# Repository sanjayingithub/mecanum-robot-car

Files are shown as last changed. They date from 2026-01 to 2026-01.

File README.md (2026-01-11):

# ESP32 Mecanum Wheel Robot Car

A complete remote-controlled mecanum wheel robot car system using ESP32 microcontrollers with ESP-NOW wireless communication protocol.

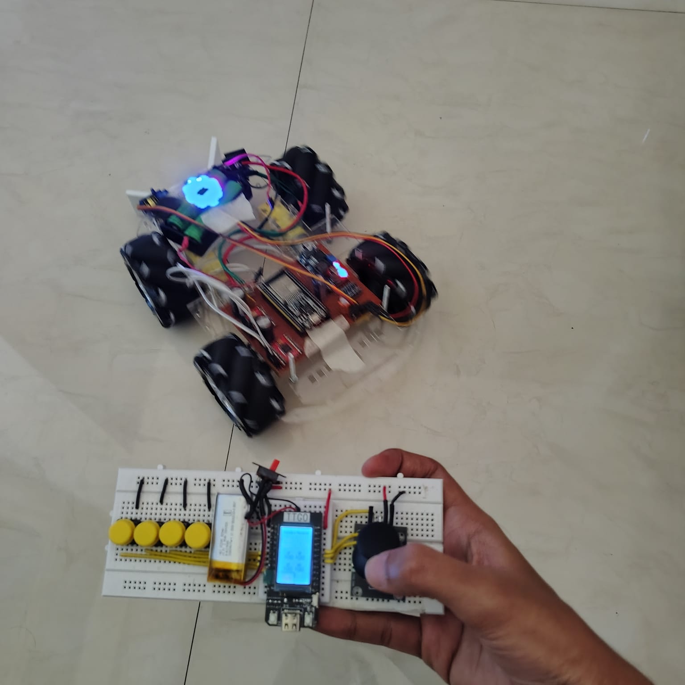
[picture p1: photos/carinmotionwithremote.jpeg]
Youtube Video (https://www.youtube.com/watch?v=mn05_ho8lYk)

Click on image for video

## 📋 Overview

This project consists of two main components:
- **Experiment_car_copy**: The robot car controller (ESP32 DevKitC)
- **ESP_NOW_remote**: The wireless remote control (TTGO T-Display)

> 📖 **For detailed build process, issues encountered, and recommendations, see [BUILD_LOG.md](BUILD_LOG.md)**

This is a derived and enhanced version of the original mecanum wheel robot car designed by [DroneBot Workshop](https://dronebotworkshop.com). Special thanks to them for the excellent tutorial!

## 🚗 Features

### Robot Car (Experiment_car_copy)
- **4-Wheel Mecanum Drive System** with omnidirectional movement
- **6 Driving Modes**:
  - Standard Mode (full directional control)
  - Rotate Mode (in-place rotation)
  - Front/Rear Pivot Modes
  - Left/Right Pivot Modes
- **8 WS2812B RGB Status LEDs**:
  - Mode indicator (cyan/green/orange/violet/light blue/yellow)
  - Battery health indicator (green/yellow/red/flashing red)
  - Flapper mechanism indicator (indigo when active)
  - Speed limiter indicator (white/magenta)
  - Motor direction indicators (blue=forward, green=reverse, red=stopped)
- **Servo-controlled Flapper Mechanism** (kick action)
- **Real-time Battery Monitoring** with voltage divider
- **Motor Control**: TB6612FNG dual motor drivers
- **Watchdog Timer** for system stability
- **ESP-NOW Communication** with signal timeout protection

### Remote Control (ESP_NOW_remote)
- **TTGO T-Display Module** with integrated TFT screen
- **Analog Joystick Control** for precise movement
- **Multiple Display Modes**:
  - Graph mode (motor speed visualization)
  - Speed display mode
  - Compact mode (portrait orientation)
- **Speed Limiter Function** (adjustable maximum speed)
- **Battery Voltage Display** (both remote and car)
- **Real-time Motor Status** visualization
- **Mode Switching Buttons** (joystick button, rotate button)
- **Screen Toggle** functionality for power saving

## 🔧 Hardware Requirements

### Robot Car
- ESP32 DevKitC (or compatible)
- 2x TB6612FNG Motor Driver Modules (or L298N)
- 4x DC BO Motors with mecanum wheels
- 1x Servo motor (for flapper mechanism)
- 8x WS2812B NeoPixel LEDs
- 2S Li-ion Battery (7.4V nominal)
- Voltage divider circuit (100kΩ + 47kΩ resistors)
- LM2596 (for stepping down the voltage to 5V for ESP32, Neopixel, servo)

### Remote Control
- TTGO T-Display ESP32 Module
- Analog Joystick Module (X/Y axis + button)
- 4 Push buttons for additional controls
- Battery (3.7V LiPo)

## 📌 Pin Connections

### Car (ESP32 DevKitC)
```
Motors:
- Right Front: PWM=19, IN1=32, IN2=23
- Left Front:  PWM=26, IN1=33, IN2=25
- Right Rear:  PWM=27, IN1=12, IN2=14
- Left Rear:   PWM=4,  IN1=13, IN2=2

NeoPixels: Pin 5
Servo: Pin 18
Battery ADC: Pin 34
```

### Remote (TTGO T-Display)
```
Joystick:
- X-Axis: Pin 33
- Y-Axis: Pin 32
- Switch: Pin 12

Buttons:
- Flap: Pin 15
- Rotate: Pin 2
- Speed Limiter: Pin 13
- Display Mode: Pin 0 (built-in)
- Screen Toggle: Pin 35 (built-in)

Battery ADC: Pin 34
```

## 🚀 Getting Started

### Prerequisites
- [PlatformIO IDE](https://platformio.org/) (VS Code extension recommended)
- USB cable for programming
- Git (for cloning repository)

### Installation

1. **Clone the repository**
   ```bash
   git clone https://github.com/yourusername/mecanum-robot-car.git
   cd mecanum-robot-car
   ```

2. **Update MAC Addresses**
   - In `Experiment_car_copy/src/main.cpp`, update line 133:
     ```cpp
     uint8_t broadcastAddress[] = {0x08,0xD1,0xF9,0x6A,0x6E,0x94}; // Remote MAC
     ```
   - In `ESP_NOW_remote/src/main.cpp`, update line 68:
     ```cpp
     uint8_t broadcastAddress[] = {0xD4,0xE9,0xF4,0xA3,0x2F,0xF4}; // Car MAC
     ```
   
   *To find MAC address: Upload a simple sketch that prints `WiFi.macAddress()`*

3. **Install Required Libraries**
   
   Libraries are automatically managed by PlatformIO. Required dependencies:
   - NeoPixelBus (for WS2812B LEDs)
   - ESP-NOW (built-in)
   - TFT_eSPI (for remote display)

4. **Configure TFT_eSPI** (Remote only)
   - Copy `TFT_eSPI_Setup.h` to your TFT_eSPI library folder
   - Or modify `User_Setup.h` in the library for TTGO T-Display

5. **Upload Code**
   ```bash
   # For the car
   cd Experiment_car_copy
   pio run --target upload
   
   # For the remote
   cd ../ESP_NOW_remote
   pio run --target upload
   ```

## 🎮 Usage

### Remote Control Operation

**Joystick:**
- Move in any direction for mecanum wheel control
- Push button to cycle through all 6 modes

**Buttons:**
- **Rotate Button**: Quick cycle (Standard → Rotate → Front Pivot)
- **Flap Button**: Activate servo flapper mechanism
- **Speed Limiter**: Toggle speed restriction on/off
- **Display Mode**: Cycle through display layouts
- **Screen Toggle**: Turn display on/off for battery saving

### LED Indicators (Car)

**Status LEDs:**
- **NEO_STATUS (0)**: Current driving mode
  - Cyan = Standard, Green = Rotate, Orange = Front Pivot
  - Violet = Rear Pivot, Light Blue = Right Pivot, Yellow = Left Pivot
- **NEO_STATUS1 (2)**: Battery health
  - Green (>7.2V), Yellow (7.0-7.2V), Red (<7.0V), Flashing Red (<6.5V)
- **NEO_STATUS2 (4)**: Flapper status
  - Indigo = Active, Mode color = Idle
- **NEO_STATUS3 (6)**: Speed limiter
  - Magenta = Limited, Mode color = Normal

**Motor LEDs:**
- Blue = Forward, Green = Reverse, Red = Stopped

**Error State:**
- All LEDs turn RED when remote connection lost (>500ms timeout)

## 🔋 Battery Monitoring

The system monitors both car and remote battery voltages:
- Car: 2S Li-ion (7.4V nominal, 6.0V cutoff)
- Remote: 1S LiPo (3.7V nominal, 3.0V cutoff)

Voltage divider calculations are calibrated in code. Adjust `batteryConversionFactor` if readings are inaccurate.

## ⚙️ Configuration

### Speed Limiter
Adjust maximum speed in `ESP_NOW_remote/src/main.cpp`:
```cpp
const int speedLimitX = 100;  // 0-254 range
const int speedLimitY = 100;
```

### Servo Settings
Flapper servo parameters in `Experiment_car_copy/src/main.cpp`:
```cpp
const int kickAngle = 50;        // Kick position (degrees)
const long kickDelay = 500;      // Kick duration (ms)
const long kickCooldown = 50;    // Cooldown time (ms)
```

### LED Brightness
Reduce brightness by adjusting RGB values in color definitions (currently set to 20%).

## 🐛 Troubleshooting

**No Communication:**
- Verify MAC addresses are correct
- Check WiFi is not interfering
- Ensure both devices powered on
- Check serial monitor for ESP-NOW init errors

**Motors Not Moving:**
- Check motor driver connections
- Verify power supply is adequate (2A+ recommended)
- Test motor drivers independently
- Check PWM channel conflicts

**LEDs Not Working:**
- Verify NeoPixel power and ground
- Check data pin connection (Pin 5)
- Remove any resistors in power rail (causes voltage drop)
- Test with simple NeoPixel sketch

**Display Issues (Remote):**
- Verify TFT_eSPI configuration
- Check backlight control (Pin TFT_BL)
- Test display with TFT_eSPI examples

## 📝 Code Structure

### Experiment_car_copy
- ESP-NOW communication callbacks
- Motor control functions (6 modes)
- LED status management
- Battery monitoring
- Servo flapper control
- Watchdog timer implementation

### ESP_NOW_remote
- Joystick input processing with deadzone
- Button debouncing logic
- Display rendering (3 modes)
- ESP-NOW data transmission
- Battery voltage monitoring

## 🤝 Contributing

Improvements welcome! Areas for enhancement:
- PID-based speed control
- IMU integration for stability
- Obstacle detection sensors
- Autonomous navigation modes
- Mobile app integration

## 📄 License

This project is open source. Feel free to modify and distribute.

## 🙏 Acknowledgments

- Based on mecanum wheel robot tutorial by [DroneBot Workshop](https://dronebotworkshop.com)
- NeoPixelBus library by Michael C. Miller
- TFT_eSPI library by Bodmer
- ESP-NOW protocol by Espressif

## 📧 Contact

For questions or suggestions, please open an issue on GitHub.

---

**Happy Building! 🤖**

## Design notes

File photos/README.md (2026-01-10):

# Build Photos

This folder contains photos documenting the build process and final assembly.

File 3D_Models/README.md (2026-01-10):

# 3D Models Directory

This folder contains STL files for custom 3D printed components used in the mecanum robot car build.

## Files

### motor_coupler.stl
- Motor shaft to wheel hub coupler
- Print with 80% infill for strength
- Material: PLA or PETG

### flapper_arm.stl
- Servo-mounted flapper mechanism for ball kicking
- Print with 80% infill
- Material: PETG recommended (more impact resistant)

## Print Settings

**Recommended:**
- Layer Height: 0.2mm
- Infill: See individual file notes
- Supports: As needed
- Raft/Brim: Use for parts with small contact area

**Notes:**
- All files designed for standard FDM printers
- No special hardware required
- Test fit before full assembly
- Sand contact surfaces for smooth fit

---

*Add your STL files to this directory*

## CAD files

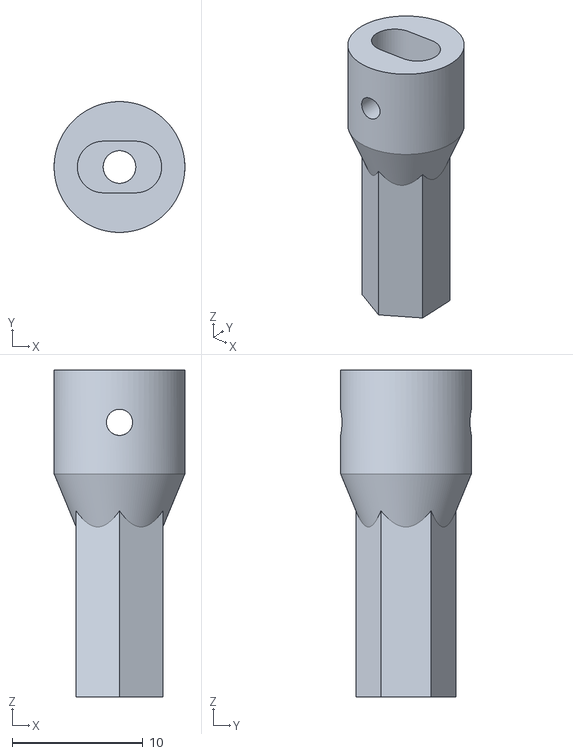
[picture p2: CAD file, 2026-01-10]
3D_Models/couplerAdityaRao.stl
10.0 x 10.0 x 25.0

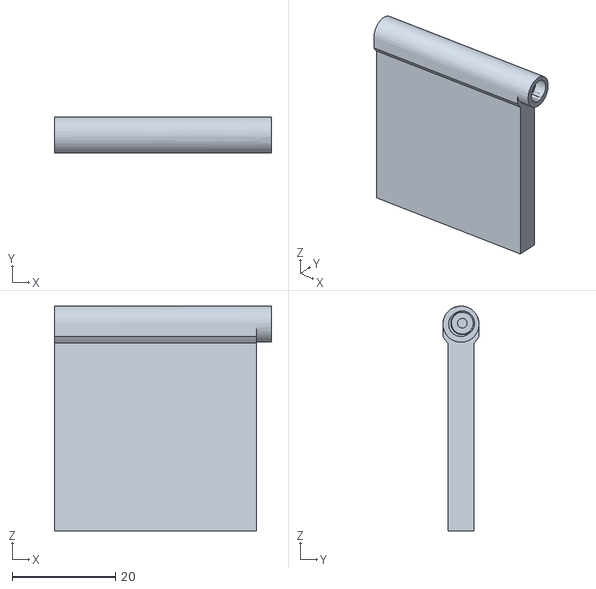
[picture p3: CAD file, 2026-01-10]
3D_Models/flapper.stl
42.0 x 7.00 x 43.5

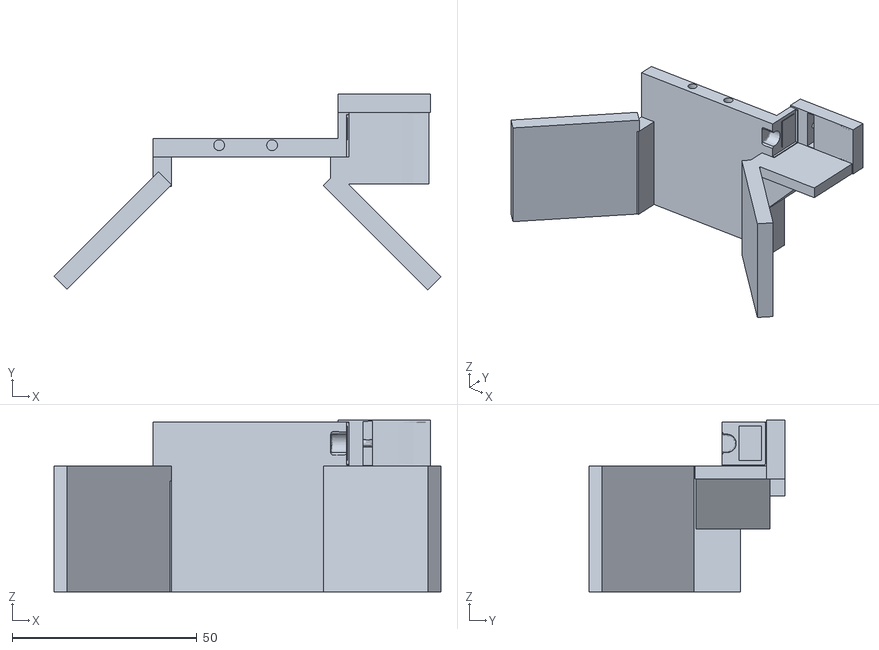
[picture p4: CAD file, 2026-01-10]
3D_Models/flapper_body.stl
104.6 x 53.0 x 46.5

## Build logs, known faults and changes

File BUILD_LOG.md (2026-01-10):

# Build Log & Documentation

## 📝 Project Overview

This is a derived and enhanced version of the Mecanum Wheel Robot Car originally designed by [DroneBot Workshop](https://dronebotworkshop.com). The original tutorial provided an excellent foundation, and this build includes several modifications and improvements based on real-world testing and usage.

**Original Tutorial:** [DroneBot Workshop - Mecanum Wheel Robot Car](https://dronebotworkshop.com/mecanum/)

> **Special Thanks:** A huge thank you to DroneBot Workshop for the comprehensive tutorial and detailed explanations that made this project possible!

#### **Another valuable resource** [IITM Student Outreach Program](https://drive.google.com/drive/folders/1NdA0Y0AUDSWe7Uvx9wfMEFJxht2Ays-z)

#### **People who help me make this into a reality**
  - Sajeev
  - Nisha
  - [Tejassh](https://github.com/TejazerX)
  - [Aditya](https://www.linkedin.com/in/aditya-mahto-55274b391/)
  - Diya ma'am
  - Jinesh sir
  - Nandana
  - [Aditya](https://www.linkedin.com/in/adityaraoiitm/)
  - [Phil](https://www.printables.com/@PhilM)

---

## 🛠️ Build Process & Modifications

### Mechanical Components

#### Frame & Chassis
- **Material:** Laser-cut acrylic/MDF panels
- **Process:** 
  - Designed frame layout for mecanum wheel configuration
  - Sent design for laser cutting service
  - **Required extensive sanding** of all cut edges to remove char marks and ensure smooth finish
  - Assembly with M3 standoffs (I wasn't able to get M3 standoffs so used 10mm screws and nuts) and screws
- **File:** [I didn't design it, got it from Phil M](https://www.printables.com/model/186945-4wd-buggy-chassis-arduino)

**💡 Recommendation:** Consider purchasing a **pre-made mecanum wheel car kit** instead of sourcing individual components. It's often:
- **Cheaper** than buying parts separately
- Comes with properly fitted parts
- Saves significant time on fabrication
- Eliminates alignment issues

Popular kit options:
- 4WD Mecanum Wheel Robot Car Kit (various sellers on AliExpress, Amazon, robu, makerbazar)
- Pre-assembled chassis with motor mounts
- Often includes motors and wheels
- Also the fittings, the screws and nuts are quite difficult to source by themself especially locally and they are more expensive too.

#### Custom 3D Printed Parts

##### 1. Motor-to-Wheel Coupler
- **Purpose:** Connect DC motors to mecanum wheel hubs
- **Material:** PLA/PETG
- **Print Settings:**
  - Layer height: 0.2mm
  - Infill: 50-80% (needs to handle torque)
  - Supports: Required for shaft interface
  - Print orientation: it in a horizontal manner as i had issues of it snapping off due to torque. 
  
**Issues Faced:**
- Initial couplers were too tight - had to sand down motor shaft interface
- Wheel wobble due to loose fit - added plumbers tape for grip
- Kept on breaking so applied M-Seal will have to fix it as the wheels aren't oriented straight.

**Files:** `3D_Models/motor_coupler.stl`  [I didn't design this,got them for IITM School connect course curriculum](https://drive.google.com/file/d/1HanFR_hteSeybVQaEPewp7Q1eFs2xh4M/view?usp=drivesdk)

##### 2. Servo Flapper Mechanism
- **Purpose:** Ball kicking mechanism mounted on servo
- **Design:**
  - Servo horn attachment point
  - Extended arm for reach
  - Reinforced impact surface
- **Material:** PETG (more flexible and impact-resistant than PLA)
- **Print Settings:**
  - Layer height: 0.2mm
  - Infill: 80% (needs strength for impacts)
  - Print orientation: Flat to ensure layer strength perpendicular to impact

**Issues Faced:**
- PLA version cracked after repeated impacts - switched to PETG
- Initial design too long - reduced servo strain by shortening arm
- Servo jitter under load - adjusted PWM frequency

**Files:** `3D_Models/flapper_arm.stl` *This is my first model so there are lots of problems, shall update it in future*

[Body](https://github.com/sanjayingithub/mecanum-robot-car/blob/main/3D_Models/flapper_body.stl)
[Flapper](https://github.com/sanjayingithub/mecanum-robot-car/blob/main/3D_Models/flapper.stl)

---

## ⚡ Electronics Assembly

### Power Distribution
- **Main Battery:** 2S Li-ion (7.4V, 2200mAh recommended)
- **Issue:** Initial setup had voltage drop under load
  - **Solution:** Added capacitors (470µF) near motor drivers
  - Used thicker gauge wires (18 AWG) for motor power

### Motor Drivers
- **Used:** 2x TB6612FNG modules
- **Mounting:** designed the entire thing on a protoboard

### LED Wiring
- **Critical Issue:** Added 220Ω resistor in NeoPixel power rail thinking it was needed
  - **Problem:** Caused voltage drop affecting blue channel brightness
  - **Solution:** Removed resistor - NeoPixels work best with direct 5V connection
  - **Lesson:** Always check component datasheets before adding "protective" components

### Servo Integration
- **Flapper Servo:** Connected to Pin 18
- **Power:** Direct from battery through servo connector
- **Issue:** Servo buzzing at idle
  - **Solution:** Adjusted duty cycle calculation for 0° position
  - Used 16-bit LEDC resolution for smoother control

---

## 🎨 Aesthetics & Finishing

### Sanding of motor mounts and 3d prints
- **Time Required:** Approximately 3-4 hours for all laser-cut parts
- **Tip:** Wet sanding works better for acrylic, prevents melting from friction

### LED Brightness Tuning
- **Initial:** Full brightness (255 RGB values)
- **Problem:** Way too bright, uncomfortable to look at
- **Solution:** Reduced to 20% brightness (51 RGB values)
- **Result:** Easier on eyes while maintaining visibility

---

## 📸 Build Photos

### Assembly Stages

#### 1. Charger
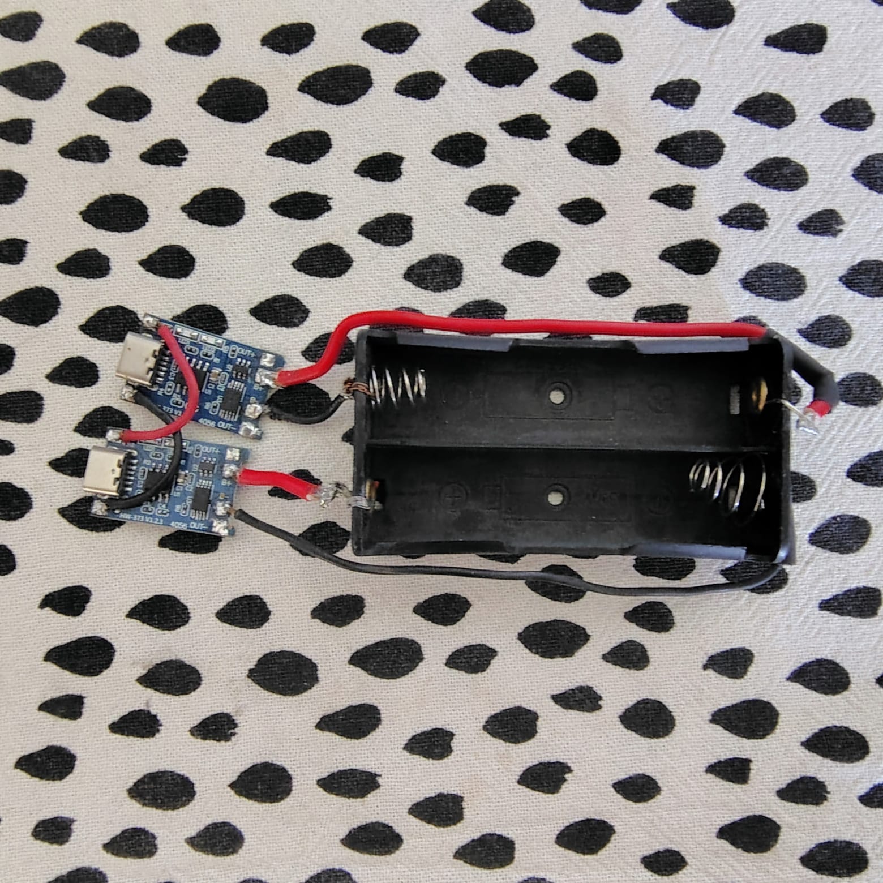
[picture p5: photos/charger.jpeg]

- Its basically TP4056 and a battery holder
- 2 of the modules are connected in parallel
- The modules doesn't have [5.1K 1% resistors in CC lines](https://forum.digikey.com/t/simple-way-to-use-usb-type-c-to-get-5v-at-up-to-3a-15w/7016) so a type A to type C cable will only work as it doesn't support PD

#### 2. Electronics Layout
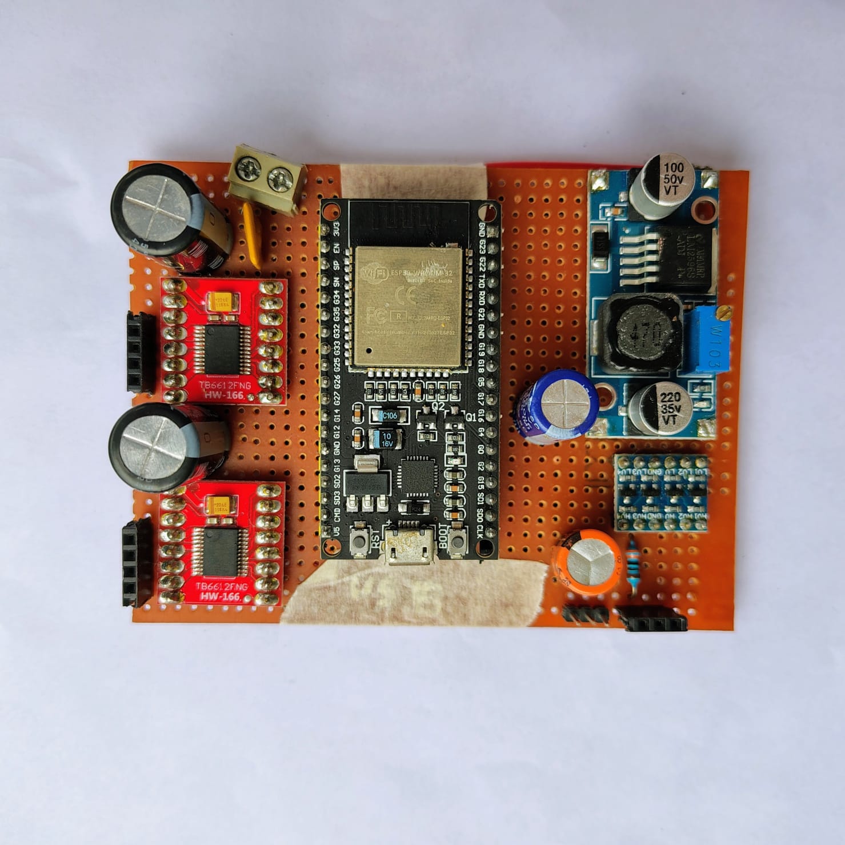
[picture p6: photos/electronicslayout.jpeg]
electronics layout

- Motor drivers positioned
- ESP32 mounted
- Wiring harness layout

#### 3. LED Neopixel
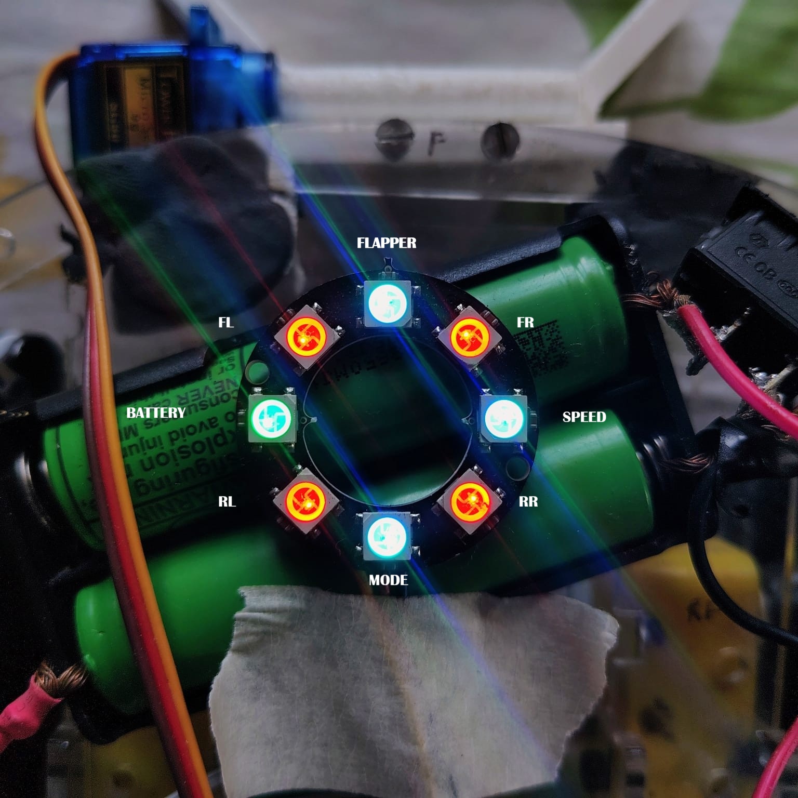
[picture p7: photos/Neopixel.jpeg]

- NeoPixel ring placement

#### 4. Flapper Mechanism
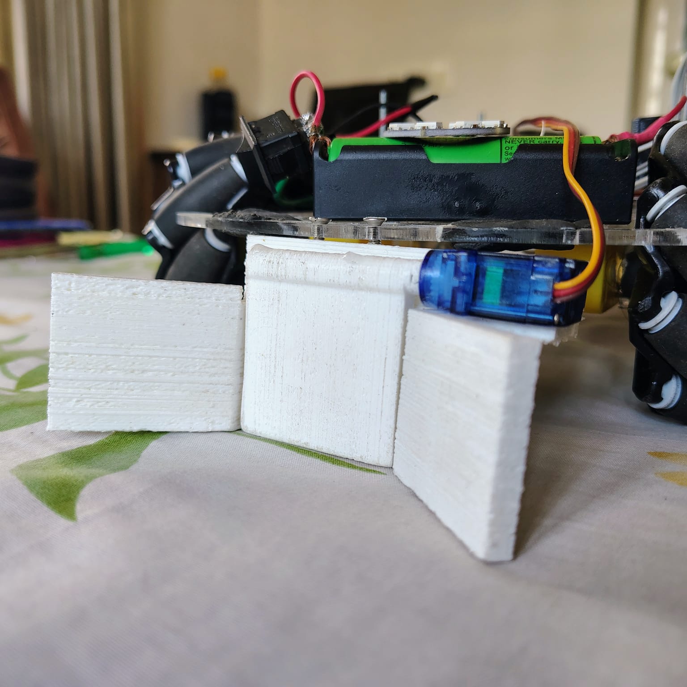
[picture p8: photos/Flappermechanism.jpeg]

- 3D printed flapper arm
- Servo mounting

#### 5. Completed Build - Top View
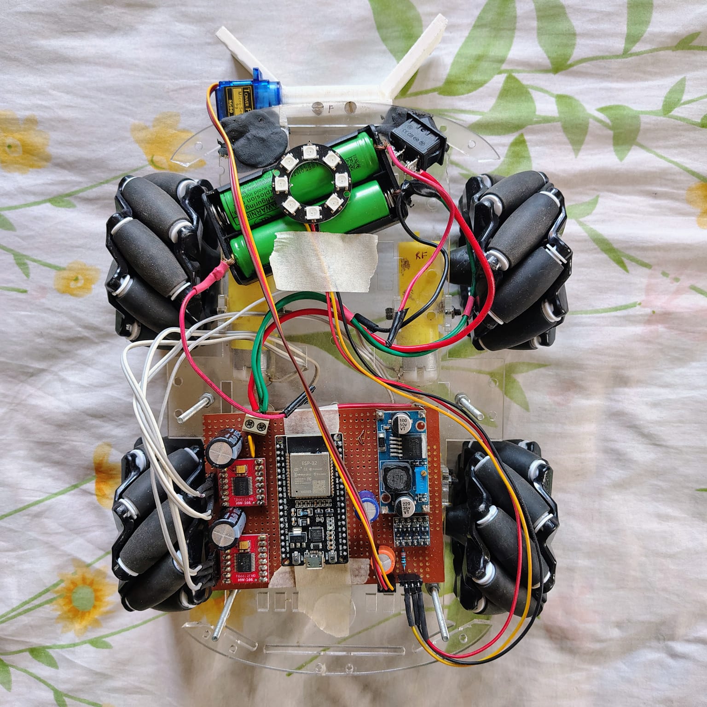
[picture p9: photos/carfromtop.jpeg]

- Fully assembled robot
- All components in place

#### 6. Completed Build - Side View
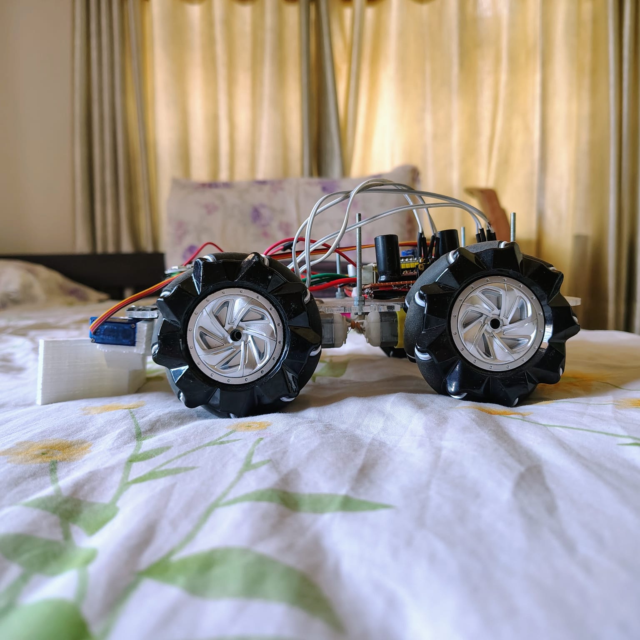
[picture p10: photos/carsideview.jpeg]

- Ground clearance

#### 7. Remote Control
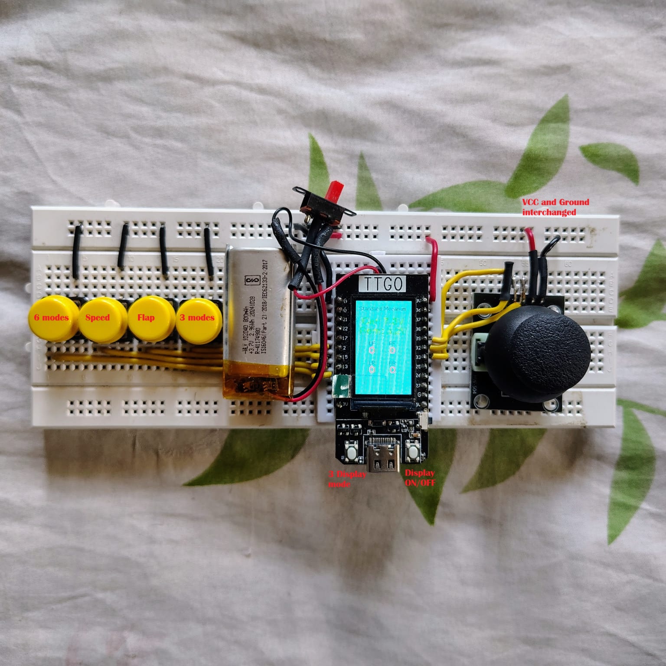
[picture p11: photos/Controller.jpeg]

- TTGO T-Display with joystick
- Button layout

#### 8. Action Shots
electronics layout
- Robot in motion
- LED indicators active
- Flapper mechanism deployed

#### 9. Display
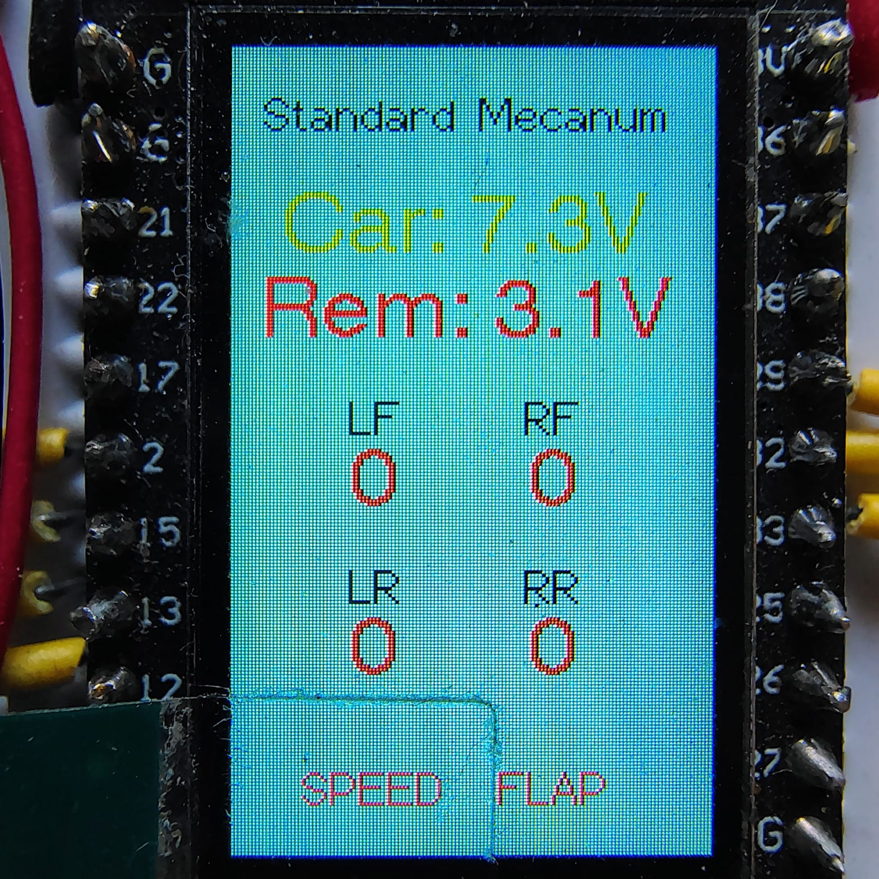
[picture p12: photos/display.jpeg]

- This is the default mode the other 2 are same as Dronebotworkshop
- The title and background color changes in differnt modes
- The colour of motor postion changes with direction and values change with speed
- Lower corner shows the indication of Speed and flapper modes

#### 10. Wiring
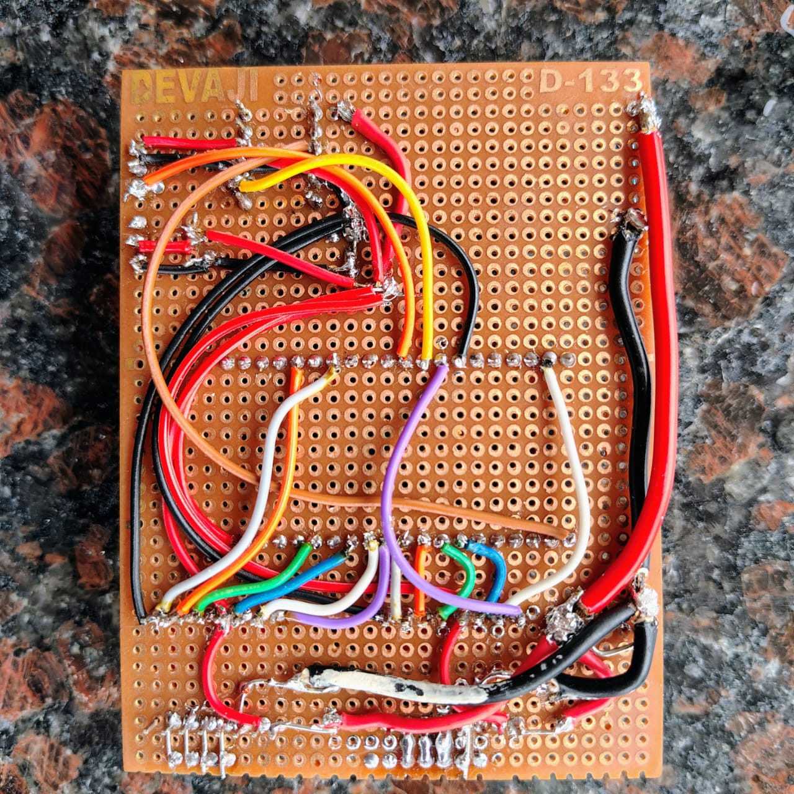
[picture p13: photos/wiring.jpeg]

- This is my first experience with protoboarding
- The soldering works even though it look like a piece of crap
- This was taken before adding the voltage divider

#### 11. Resistive divider
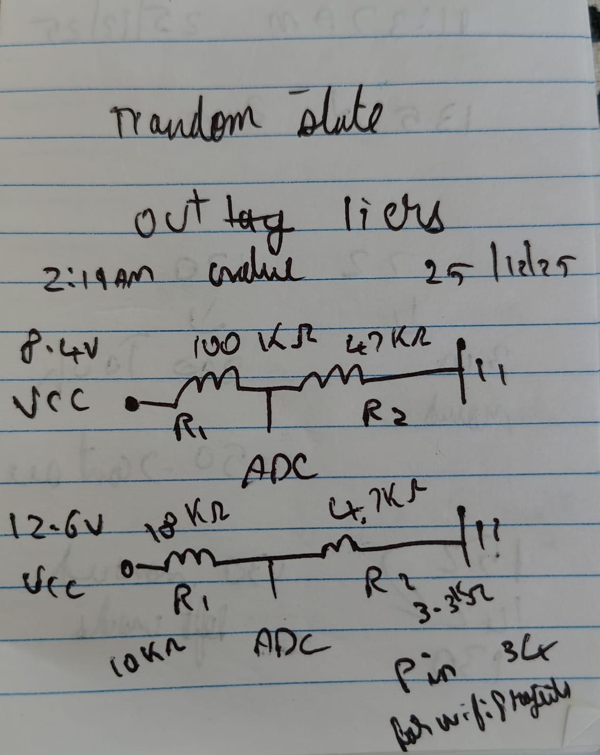
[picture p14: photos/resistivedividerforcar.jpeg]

- The first resistor values are being used here as 2 18650 batteries are only used
- If you decide to go with 3 18650 in series use the second resistor values

#### 12. Pin marking
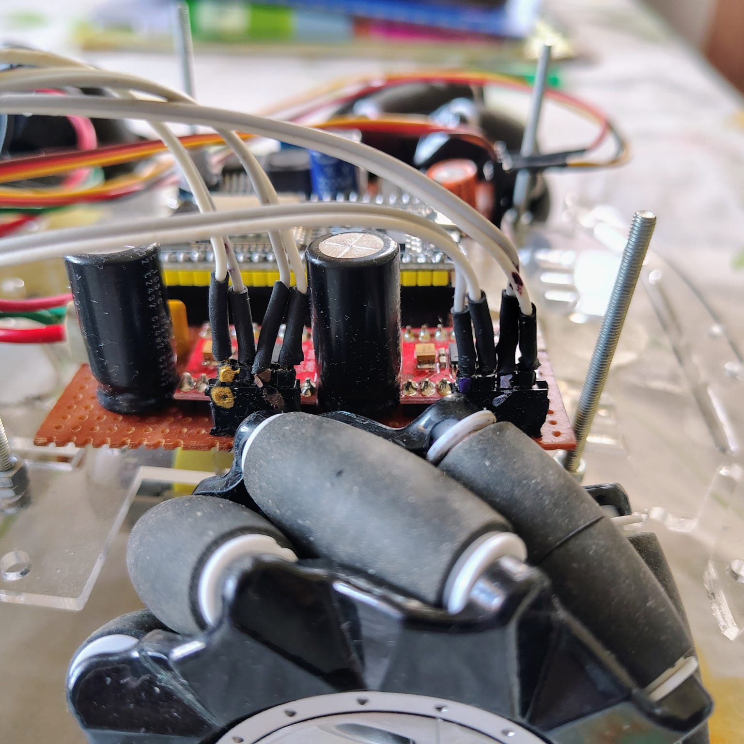
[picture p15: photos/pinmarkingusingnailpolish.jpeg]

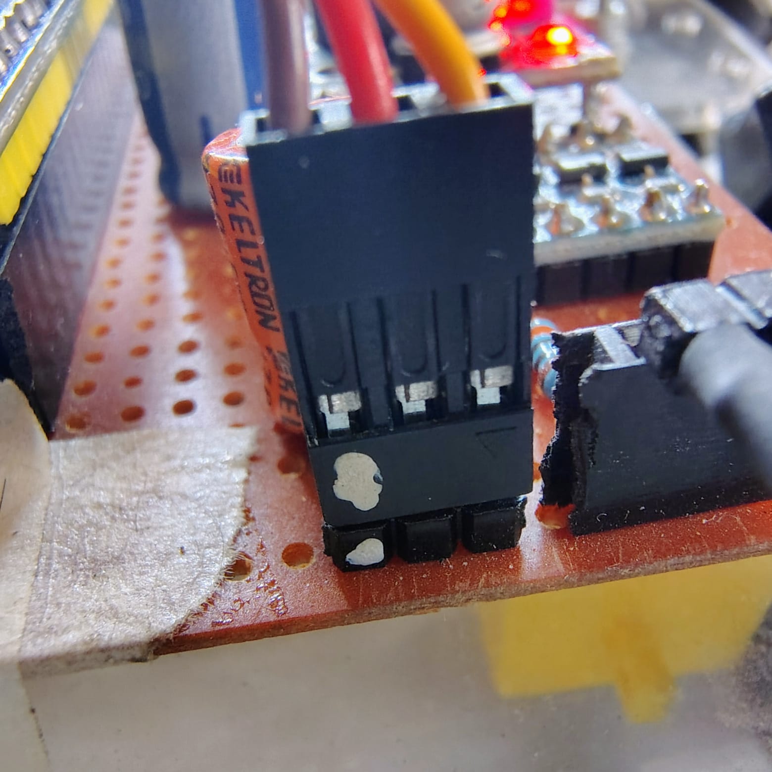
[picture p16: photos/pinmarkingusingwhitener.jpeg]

- Used a combination of whitener and nail polish to oriet and connect the wires.

---

## 🐛 Issues Encountered & Solutions

### Hardware Issues

#### 1. Motor Alignment
**Problem:** Mecanum wheels not driving straight
- **Cause:** Uneven motor mounting, wheels not perfectly perpendicular
- **Solution:** 
  - The plan is it print the couplers again and tweak the design and motor mounting method.
  - If that that doesn't work might implement software based solutions.

#### 2. Wheel Wobble
**Problem:** Visible wobble in wheels during rotation
- **Cause:** Loose coupler fit
- **Solution:**
  - Redesigned couplers with tighter tolerances
  - Used plumbers tape for vibration dampening
  - Checked motor shaft straightness before installation

#### 3. Protection
**Problem:** Over current draw
- **Cause:** Short circuit
- **Solution:**
  - RUSBF250 16V 2.5A Tyco Raychem PPTC resettable fuse
  - Added series to the battery
  - Cuts off it too much current is drawn

### Software Issues

#### 4. LED Flickering (Flapper Indicator)
**Problem:** LED status not staying on during flapper activation
- **Cause:** Status update function overwriting LED every loop
- **Solution:** 
  - Added state protection in `setLedStatus()`
  - Continuous LED state refresh in `flapper()` function
  - Separate LED control during kick/cooldown states

#### 5. Color Synchronization
**Problem:** Car LED colors didn't match remote display
- **Cause:** Different mode-to-color mappings between devices
- **Solution:** Standardized color scheme across both programs

#### 6. Blue Channel Dimness
**Problem:** Blue LEDs appeared significantly dimmer than red/green
- **Initially thought:** LED characteristic issue
- **Actual cause:** 220Ω resistor in power rail causing voltage drop
- **Solution:** Removed resistor, blue channel returned to normal

### Communication Issues

#### 7. ESP-NOW Connection Drops
**Problem:** Intermittent disconnections during operation
- **Cause:** WiFi interference, power supply instability
- **Solution:**
  - Disabled WiFi sleep mode: `WiFi.setSleep(false)`
  - Added watchdog timer for system recovery
  - Implemented proper timeout handling (500ms)

#### 8. Joystick Drift
**Problem:** Car slowly drifting even with joystick centered
- **Cause:** Analog joystick calibration, electrical noise
- **Solution:**
  - Implemented deadzone (±200 ADC counts) in `convertJoystickValues()`
  - Software filtering for stability

---

## 💡 Recommendations & Tips

### For Future Builders

#### 1. **Buy a Kit Instead of Individual Parts**
   - **Cost:** Often 30-50% cheaper than sourcing separately
   - **Time:** Saves weeks of waiting for parts from different suppliers
   - **Quality:** Parts designed to work together
   - **Less headache:** No compatibility issues

#### 2. **3D Printing Tips**
   - Print couplers with high infill (80%+) for strength
   - Use PETG for impact parts (flapper)
   - Print orientation matters - consider layer strength
   - Keep spare printed parts for quick replacement

#### 3. **Electronics Assembly**
   - **Test components individually** before final assembly
   - Use JST connectors for easy disconnect/reconnect or go cheap with berg at your own risk
   - Label all wires (seriously, do this!) nail polish could also work
   - Take photos during assembly for reference

#### 4. **Power Management**
   - Use proper capacity battery (2200mAh minimum) 
   - Add voltage monitoring early in development
   - Include power switch in accessible location
   - Consider adding a fuse for protection
   - Don't buy those cheap knock off batteries use name brand once

#### 5. **LED Brightness**
   - Start with low brightness (20-30%) and increase if needed
   - Much easier to increase than decrease
   - Consider ambient lighting conditions

#### 6. **Software Development**
   - Use version control (Git) from the start
   - Comment your code thoroughly
   - Test each feature independently
   - Keep a changelog of modifications

---

## 🔮 Future Enhancements

### Planned Upgrades
- [ ] Add IMU (MPU6050) for stability control
- [ ] Implement PID speed control for accurate movements
- [ ] Add ultrasonic sensors for obstacle detection
- [ ] Create autonomous navigation mode
- [ ] Add FPV camera module
- [ ] Implement mobile app control (Bluetooth/WiFi)
- [ ] Add line-following capability
- [ ] Improve battery life optimization

### Ideas Under Consideration
- Additional servo for grabber arm
- Encoder-based odometry
- Custom PCB to consolidate wiring

---

## 📚 Resources & References

### Original Tutorial
- **DroneBot Workshop:** https://dronebotworkshop.com
- YouTube tutorial series on mecanum wheel robots
- Excellent explanations of mecanum wheel mathematics

### Libraries Used
- **NeoPixelBus** by Michael C. Miller: https://github.com/Makuna/NeoPixelBus
- **TFT_eSPI** by Bodmer: https://github.com/Bodmer/TFT_eSPI
- **ESP-NOW** documentation: https://docs.espressif.com/projects/esp-idf/en/latest/esp32/api-reference/network/esp_now.html

### Helpful Resources
- ESP32 pinout reference
- Mecanum wheel kinematics tutorials
- PlatformIO documentation
- WS2812B datasheet

---

## 📞 Contact & Contributions

This project is open source and contributions are welcome!

**Found an issue?** Open an issue on GitHub
**Have improvements?** Submit a pull request
**Questions?** Start a discussion

---

## 🎉 Conclusion

This project has been an incredible learning experience, combining mechanical design, electronics, and embedded programming. While challenging at times (especially the sanding!), the end result is a highly capable and fun robot platform.

**Key Takeaways:**
1. **Buy a kit if possible** - saves time and money
2. **Test early and often** - catch issues before final assembly
3. **Document everything** - future you will thank present you
4. **Community resources are invaluable** - thank you DroneBot Workshop!
5. **Iterate and improve** - first version doesn't have to be perfect

**Total Project Rating:** ⭐⭐⭐⭐⭐ (5/5)
- Fun factor: ⭐⭐⭐⭐⭐
- Learning value: ⭐⭐⭐⭐⭐
- Difficulty: ⭐⭐⭐⭐ (4/5)
- Cost effectiveness: ⭐⭐⭐ (3/5 - kit would be better)

**Would I build it again?** Absolutely! But with a kit next time. 😄

---

*Last Updated: January 9, 2026*
*Build by: Sanjay Sajeev*

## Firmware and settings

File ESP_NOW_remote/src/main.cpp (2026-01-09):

/*
  4WD Mecanum Wheel Remote Control
  mec-robot-remote.ino
  Controls 4-wheel mecanum car base
  Uses ESP32 TTGO "T-Display" module with integrated TFT display and 2 pushbuttons 
  Uses ESP-NOW library
  Uses TFT_eSPI Library by Bodmer - https://github.com/Bodmer/TFT_eSPI
  Modify User_Setup.h file in library for TTGO-T-Display
  
  DroneBot Workshop 2022
  https://dronebotworkshop.com
*/

#include <Arduino.h>

// Include Libraries for ESP-NOW Communications
#include <esp_now.h>
#include <WiFi.h>

// Include libraries for display
#include <TFT_eSPI.h>
#include <SPI.h>

// Define Joystick Connections (some joystick models reverse X & Y)
#define X_AXIS_PIN 33
#define Y_AXIS_PIN 32
#define SWITCH_PIN 12
#define FLAP_PIN 15
#define ROTATE_PIN 2
#define SPEED_PIN 13
#define LAST_PIN 39

// Speed limiter max values (0-254 range)
const int speedLimitX = 100;
const int speedLimitY = 100;

// Battery voltage monitoring
#define BATTERY_PIN 34  // ADC pin for battery voltage divider
const float voltageConversionFactor = 2.0;  // Adjust based on voltage divider ratio
float remoteBatteryVoltage = 0.0;

// Battery voltage thresholds for color coding
const float CAR_BATTERY_THRESHOLD = 7.00;
const float REMOTE_BATTERY_THRESHOLD = 3.10;

// Define TTGO display built-in pushbuttons
#define BUTTON_DISPLAY_MODE 0    // Cycles through display modes
#define BUTTON_SCREEN_TOGGLE 35   // Turns screen on/off

// Objects for display & sprites
TFT_eSPI tft = TFT_eSPI();
TFT_eSprite sprite = TFT_eSprite(&tft);

// Display colors
#define displayColor1 0xFFFF  // White

#define displayColor2a 0x1E1E  // Cyan
#define displayColor2b 0x5566  // Green
#define displayColor2c 0xE3E3  // Orange
#define displayColor2d 0xFAFA  // Violet
#define displayColor2e 0xBEBE  // Light Blue
#define displayColor2f 0xE6E6  // Yellow

#define displayColor3 0x0000  // Black
#define displayColor4 0x2727  // Green Bar
#define displayColor5 0x1B1B  // Blue Bar
#define displayColor6 0xE8E8  // Red

// MAC Address of responder - edit as required
uint8_t broadcastAddress[] = { 0xD4, 0xE9, 0xF4, 0xA3, 0x2F, 0xF4 };

// Define a data structure for received data
typedef struct struct_message_rcv {
  bool motorMode;
  int mecanumMode;
  int mtrRF_PWM;
  int mtrLF_PWM;
  int mtrRR_PWM;
  int mtrLR_PWM;
  float batteryVoltage;
} struct_message_rcv;

// Create a structured object for received data
struct_message_rcv rcvData;

// Create a structured object for sent data
typedef struct struct_message_xmit {
  int xAxis;
  int yAxis;
  bool pbSwitch;
  bool flap;
  bool rotate;
  bool last;
  bool speedLimitActive;
} struct_message_xmit;

// Create a structured object for sent data
struct_message_xmit xmitData;

// ESP-NOW Peer info
esp_now_peer_info_t peerInfo;

// Variable for Motor Mode
volatile byte motorModeValue = B00000000;

// Variable for Mecanum Mode
volatile int mecanumModeValue = 0;

// Variables for Motor PWM speeds
volatile int mtrRFpwmValue = 0;
volatile int mtrLFpwmValue = 0;
volatile int mtrRRpwmValue = 0;
volatile int mtrLRpwmValue = 0;

// Variable for battery voltage
volatile float batteryVoltage = 0.0;

// Variables for Joystick values
int joyXaxis = 127;
int joyYaxis = 127;

// Variable for Joystick pushbutton state
bool joySwitchState = HIGH;
bool flapState = HIGH;
bool rotate = HIGH;
bool last = HIGH;

// Speed limiter toggle state
bool speedLimitActive = false;

// Debounce delay in milliseconds
const unsigned long debounceDelay = 10;

// Button state tracking structure
struct ButtonState {
  bool lastReading;
  bool currentState;
  unsigned long lastDebounceTime;
  bool lastStableState;
};

ButtonState switchBtn = {HIGH, HIGH, 0, HIGH};
ButtonState rotateBtn = {HIGH, HIGH, 0, HIGH};
ButtonState speedBtn = {HIGH, HIGH, 0, HIGH};
ButtonState displayModeBtn = {HIGH, HIGH, 0, HIGH};
ButtonState screenToggleBtn = {HIGH, HIGH, 0, HIGH};
ButtonState lastBtn = {HIGH, HIGH, 0, HIGH};

// Variable for connection error  - HIGH is error state
volatile bool connectError = LOW;

// Variable for connection status string
String connectStatus = "NO INFO";

// Variable for display selection - 0 = Graph, 1 = Speed Display, 2 = Compact
volatile int displaySelect = 2;

// Variable for screen on/off state
volatile bool screenOn = true;

// Function declarations
int convertJoystickValues(int value, bool reverse);
void OnDataSent(const uint8_t *mac_addr, esp_now_send_status_t status);
void OnDataRecv(const uint8_t *mac, const uint8_t *incomingData, int len);
void graphMotorSpeed(int opMode);
void displayMotorSpeed(int opMode);
void displayCompactMode(int opMode);
void splashScreen(String messageString, bool errStat);
void controlInfo();

// Debounced button read with edge detection
// Returns true only on button release (rising edge after debounce)
bool readButtonRelease(int pin, ButtonState &btnState) {
  bool reading = digitalRead(pin);
  bool buttonReleased = false;
  
  // If reading changed, reset debounce timer
  if (reading != btnState.lastReading) {
    btnState.lastDebounceTime = millis();
  }
  
  // Check if reading has been stable for debounce delay
  if ((millis() - btnState.lastDebounceTime) > debounceDelay) {
    // Update current state if it changed
    if (reading != btnState.currentState) {
      btnState.currentState = reading;
    }
    
    // Detect rising edge (button release, since INPUT_PULLUP)
    if (btnState.currentState == HIGH && btnState.lastStableState == LOW) {
      buttonReleased = true;
    }
    
    btnState.lastStableState = btnState.currentState;
  }
  
  btnState.lastReading = reading;
  return buttonReleased;
}

// Read remote battery voltage from built-in voltage divider
float readRemoteBatteryVoltage() {
  int adcValue = analogRead(BATTERY_PIN);
  // Convert ADC value (0-4095 for 12-bit) to voltage
  // Reference voltage is typically 3.3V
  float voltage = (adcValue / 4095.0) * 3.3 * voltageConversionFactor;
  
  // // Debug output
  // Serial.print("ADC Value: ");
  // Serial.print(adcValue);
  // Serial.print(" | Voltage: ");
  // Serial.print(voltage, 2);
  // Serial.println("V");
  
  return voltage;
}

// Interrupt Service Routines removed - using debounced polling instead

void setup() {
  // Set up Serial Monitor
  Serial.begin(115200);

  // Set joystick pin as input with Pullup
  pinMode(SWITCH_PIN, INPUT_PULLUP);
  pinMode(FLAP_PIN, INPUT_PULLUP);
  pinMode(ROTATE_PIN, INPUT_PULLUP);
  pinMode(SPEED_PIN, INPUT_PULLUP);
  pinMode(LAST_PIN, INPUT_PULLUP);

  // Set built-in pushbuttons as inputs with pullups
  pinMode(BUTTON_DISPLAY_MODE, INPUT_PULLUP);
  pinMode(BUTTON_SCREEN_TOGGLE, INPUT_PULLUP);

  // Set up backlight pin
  pinMode(TFT_BL, OUTPUT);
  digitalWrite(TFT_BL, HIGH);  // Turn on backlight initially

  // Set ESP32 as a Wi-Fi Station
  WiFi.mode(WIFI_STA);

  // Disable WiFi Sleep mode
  WiFi.setSleep(false);

  // Initilize ESP-NOW
  if (esp_now_init() != ESP_OK) {
    connectStatus = "ESP-NOW Error";
    connectError = HIGH;
    return;
  } else {
    connectStatus = "ESP-NOW OK";
    connectError = LOW;
  }

  // Register receive callback function
  esp_now_register_recv_cb(OnDataRecv);

  // Register the send callback
  esp_now_register_send_cb(OnDataSent);

  // Register peer
  memcpy(peerInfo.peer_addr, broadcastAddress, 6);
  peerInfo.channel = 0;
  peerInfo.encrypt = false;

  // Add peer
  if (esp_now_add_peer(&peerInfo) != ESP_OK) {
    connectStatus = "No peer added";
    connectError = HIGH;
    return;
  } else {
    connectStatus = "ESP-NOW Ready";
    connectError = LOW;
  }

  // Set A/D resolution to 12-bits
  analogReadResolution(12);

  // Initialize the display
  tft.init();
  tft.setRotation(1);

  // Create a sprite
  sprite.createSprite(320, 170);

  // Display a splash screen
  splashScreen(connectStatus, connectError);
  delay(2000);
  connectStatus = "Waiting for car";
  splashScreen(connectStatus, connectError);
  delay(2000);

  // Enter the Loop with connectError set HIGH to avoid intial display flicker
  connectError = HIGH;
}

void loop() {

  // Check screen toggle button with debouncing (toggle on release) - works everywhere
  if (readButtonRelease(BUTTON_SCREEN_TOGGLE, screenToggleBtn)) {
    screenOn = !screenOn;
  }
  
  // Always print battery voltage for testing (regardless of connection)
  int adcRaw = analogRead(BATTERY_PIN);
  float testVoltage = (adcRaw / 4095.0) * 3.3 * voltageConversionFactor;
  Serial.print("Remote ADC: ");
  Serial.print(adcRaw);
  Serial.print(" | Voltage: ");
  Serial.print(testVoltage, 2);
  Serial.print("V | Connected: ");
  Serial.println(connectError == LOW ? "YES" : "NO");

  // Check connection status
  if (connectError == LOW) {

    // Read remote battery voltage
    remoteBatteryVoltage = readRemoteBatteryVoltage();
    
    // Print received car battery voltage for comparison
    Serial.print("Car Battery: ");
    Serial.print(batteryVoltage, 2);
    Serial.println("V");
    Serial.println("---");

    // Check if screen is on before displaying
    if (screenOn) {
      // Turn on backlight
      digitalWrite(TFT_BL, HIGH);
      
      // Select display
      if (displaySelect == 0) {
        // Ensure landscape mode for graph
        tft.setRotation(1);
        sprite.deleteSprite();
        sprite.createSprite(320, 170);
        // Display motor speed graph
        graphMotorSpeed(mecanumModeValue);
      } else if (displaySelect == 1) {
        // Ensure landscape mode for speed animation
        tft.setRotation(1);
        sprite.deleteSprite();
        sprite.createSprite(320, 170);
        // Display motor speed "animation"
        displayMotorSpeed(mecanumModeValue);
      } else {
        // Switch to portrait mode for compact display
        tft.setRotation(0);
        sprite.deleteSprite();
        sprite.createSprite(170, 320);
        // Display compact mode
        displayCompactMode(mecanumModeValue);
      }
    } else {
      // Screen is off - clear display and turn off backlight
      digitalWrite(TFT_BL, LOW);
      sprite.fillSprite(displayColor3);
      sprite.pushSprite(0, 0);
    }

    // Get joystick values and convert them
    joyXaxis = convertJoystickValues(analogRead(X_AXIS_PIN), false);
    joyYaxis = convertJoystickValues(analogRead(Y_AXIS_PIN), false);

    // Apply speed limiter if active
    if (speedLimitActive) {
      // Cap values at configured limits (scale from 0-254 range to 0-limit range)
      joyXaxis = map(joyXaxis, 0, 254, 127-(speedLimitX/2), 127+(speedLimitX/2));
      joyYaxis = map(joyYaxis, 0, 254, 127-(speedLimitY/2), 127+(speedLimitY/2));
    }

  } else {
    // Check if screen is on before displaying splash screen
    if (screenOn) {
      digitalWrite(TFT_BL, HIGH);
      // Ensure landscape mode for splash screen
      tft.setRotation(1);
      sprite.deleteSprite();
      sprite.createSprite(320, 170);
      splashScreen(connectStatus, HIGH);
    } else {
      digitalWrite(TFT_BL, LOW);
      sprite.fillSprite(displayColor3);
      sprite.pushSprite(0, 0);
    }

    // Send "zero" values as joystick data
    joyXaxis = 127;
    joyYaxis = 127;
  }

  // Check mode switch button with debouncing (trigger on release)
  if (readButtonRelease(SWITCH_PIN, switchBtn)) {
    joySwitchState = true;
  } else {
    joySwitchState = false;
  }

  // Check flap button (direct read for continuous action)
  if (digitalRead(FLAP_PIN) == LOW) {
    flapState = true;
  } else {
    flapState = false;
  }

  // Check rotate button with debouncing (trigger on release)
  if (readButtonRelease(ROTATE_PIN, rotateBtn)) {
    rotate = true;
  } else {
    rotate = false;
  }

  // Check last button with debouncing (trigger on release)
  if (readButtonRelease(LAST_PIN, lastBtn)) {
    last = true;
  } else {
    last = false;
  }

  // Check speed limit button with debouncing (toggle on release)
  if (readButtonRelease(SPEED_PIN, speedBtn)) {
    speedLimitActive = !speedLimitActive;
  }

  // Check display mode button with debouncing (cycle on release)
  if (readButtonRelease(BUTTON_DISPLAY_MODE, displayModeBtn)) {
    displaySelect = (displaySelect + 1) % 3;
  }

  // Format structured data
  xmitData.xAxis = joyXaxis;
  xmitData.yAxis = joyYaxis;
  xmitData.pbSwitch = joySwitchState;
  xmitData.flap = flapState;
  xmitData.rotate = rotate;
  xmitData.last = last;
  xmitData.speedLimitActive = speedLimitActive;

  // Send message via ESP-NOW
  esp_err_t result = esp_now_send(broadcastAddress, (uint8_t *)&xmitData, sizeof(xmitData));

  // Small delay for loop timing
  if (rotate == true) {
    delay(100);
  } else {
    delay(10);
  }
}

/*
  Mecanum Wheel Remote Control - functions
  a_remote-functions.ino
  Functions for remote control
  
  DroneBot Workshop 2022
  https://dronebotworkshop.com
*/
// Map 12-bit A/D values to 8-bit PWM values
// Allow for gap in center to account for joystick inaccuracies
int convertJoystickValues(int value, bool reverse) {
  if (value >= 2200) {
    // Joystick pushed forward
    value = map(value, 2200, 4095, 127, 254);
  } else if (value <= 1800) {
    // Joystick pulled back
    value = map(value, 1800, 0, 127, 0);
  } else {
    // Joystick in center
    value = 127;
  }

  // Check direction
  if (reverse) {
    value = 254 - value;
  }
  return value;
}

/*
  Mecanum Wheel Remote Control - ESP-NOW Callbacks
  b_callbacks.ino
  Callbacks for communication with mecanum wheel robot car
  
  DroneBot Workshop 2022
  https://dronebotworkshop.com
*/
// Callback function called when data is sent
void OnDataSent(const uint8_t *mac_addr, esp_now_send_status_t status) {

  if (status == ESP_NOW_SEND_SUCCESS) {
    connectStatus = "Car found";
    connectError = LOW;
  } else {
    connectStatus = "Car not found";
    connectError = HIGH;
  }
}

// Callback function executed when data is received
void OnDataRecv(const uint8_t *mac, const uint8_t *incomingData, int len) {

  // Get receievd data
  memcpy(&rcvData, incomingData, sizeof(rcvData));

  // Pass received values to local variables
  motorModeValue = rcvData.motorMode;
  mecanumModeValue = rcvData.mecanumMode;
  mtrRFpwmValue = rcvData.mtrRF_PWM;
  mtrLFpwmValue = rcvData.mtrLF_PWM;
  mtrRRpwmValue = rcvData.mtrRR_PWM;
  mtrLRpwmValue = rcvData.mtrLR_PWM;
  batteryVoltage = rcvData.batteryVoltage;

  //Serial.println(mecanumModeValue);
}

/*
  Mecanum Wheel Remote Control - TFT Display Graph Functions
  c_graphs.ino
  Graphs used on remote control TFT display
  
  DroneBot Workshop 2022
  https://dronebotworkshop.com
*/

void graphMotorSpeed(int opMode) {
  // Display motor speeds as bargarph
  // Background color changes with operating mode
  // Graph colors change with motor direction

  int backColor;
  String headerText;

  if (opMode == 0) {
    backColor = displayColor2a;
    headerText = "Standard Mecanum Mode";
  } else if (opMode == 1) {
    backColor = displayColor2b;
    headerText = "Rotate Mode";
  } else if (opMode == 2) {
    backColor = displayColor2c;
    headerText = "Pivot Front Mode";
  } else if (opMode == 3) {
    backColor = displayColor2d;
    headerText = "Pivot Rear Mode";
  } else if (opMode == 4) {
    backColor = displayColor2e;
    headerText = "Pivot Right Mode";
  } else if (opMode == 5) {
    backColor = displayColor2f;
    headerText = "Pivot Left Mode";
  } else {
    backColor = displayColor2f;
    headerText = "Standard Mecanum Mode";
  }


  // Fill the sprite with color & add rectangles
  sprite.fillSprite(displayColor3);
  sprite.fillRect(0, 0, 300, 160, displayColor1);
  sprite.fillRoundRect(5, 20, 230, 110, 5, backColor);
  sprite.fillRect(40, 30, 2, 80, displayColor1);
  sprite.fillRect(40, 110, 190, 2, displayColor1);

  // Text for top
  sprite.setTextDatum(4);
  sprite.setTextColor(displayColor3, displayColor1);
  sprite.drawString(headerText, 114, 10, 2);

  // Text for left sidebar (increment lables)
  sprite.setTextColor(displayColor1, backColor);
  for (int i = 2; i < 8; i = i + 2) {
    sprite.drawString(String(i * 40), 22, 105 - (i * 10));
    for (int j = 0; j < 197; j = j + 5)
      sprite.drawPixel(40 + j, 105 - (i * 10), displayColor1);
  }

  // Text for bottom
  sprite.drawString("RF", 70, 121, 2);
  sprite.drawString("LF", 115, 121, 2);
  sprite.drawString("RR", 160, 121, 2);
  sprite.drawString("LR", 205, 121, 2);

  // Display battery voltages in top right corner
  // sprite.setTextColor(displayColor1, displayColor3);
  // sprite.setTextDatum(8);  // Right aligned
  // String carBatteryText = "Car: " + String(batteryVoltage, 1) + "V";
  // String remoteBatteryText = "Rem: " + String(remoteBatteryVoltage, 1) + "V";
  // sprite.drawString(carBatteryText, 100, 50, 2);
  // sprite.drawString(remoteBatteryText, 150, 100, 2);
  // sprite.setTextDatum(4);  // Reset to center aligned

  // Bargraph values

  byte barMotorMode = motorModeValue;

  int barvalueRF = abs(mtrRFpwmValue);
  int barvalueLF = abs(mtrLFpwmValue);
  int barvalueRR = abs(mtrRRpwmValue);
  int barvalueLR = abs(mtrLRpwmValue);

  // Map results to bargraph range
  barvalueRF = map(barvalueRF, 0, 255, 0, 75);
  barvalueLF = map(barvalueLF, 0, 255, 0, 75);
  barvalueRR = map(barvalueRR, 0, 255, 0, 75);
  barvalueLR = map(barvalueLR, 0, 255, 0, 75);

  // Set bargraph colors by motor direction
  if ((bitRead(barMotorMode, 7) == 1) && (bitRead(barMotorMode, 6) == 0)) {
    sprite.fillRect(60, 110 - barvalueRF, 16, barvalueRF, displayColor5);
  } else if ((bitRead(barMotorMode, 7) == 0) && (bitRead(barMotorMode, 6) == 1)) {
    sprite.fillRect(60, 110 - barvalueRF, 16, barvalueRF, displayColor4);
  }

  if ((bitRead(barMotorMode, 5) == 1) && (bitRead(barMotorMode, 4) == 0)) {
    sprite.fillRect(105, 110 - barvalueLF, 16, barvalueLF, displayColor5);
  } else if ((bitRead(barMotorMode, 5) == 0) && (bitRead(barMotorMode, 4) == 1)) {
    sprite.fillRect(105, 110 - barvalueLF, 16, barvalueLF, displayColor4);
  }

  if ((bitRead(barMotorMode, 3) == 1) && (bitRead(barMotorMode, 2) == 0)) {
    sprite.fillRect(150, 110 - barvalueRR, 16, barvalueRR, displayColor5);
  } else if ((bitRead(barMotorMode, 3) == 0) && (bitRead(barMotorMode, 2) == 1)) {
    sprite.fillRect(150, 110 - barvalueRR, 16, barvalueRR, displayColor4);
  }

  if ((bitRead(barMotorMode, 1) == 1) && (bitRead(barMotorMode, 0) == 0)) {
    sprite.fillRect(195, 110 - barvalueLR, 16, barvalueLR, displayColor5);
  } else if ((bitRead(barMotorMode, 1) == 0) && (bitRead(barMotorMode, 0) == 1)) {
    sprite.fillRect(195, 110 - barvalueLR, 16, barvalueLR, displayColor4);
  }

  // Paint display
  sprite.pushSprite(0, 0);
}
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

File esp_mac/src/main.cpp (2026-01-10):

#include <Arduino.h>
#include <WiFi.h>

void setup() {
  Serial.begin(115200);
  delay(1000);
  Serial.println();
  
  // Set WiFi mode to station
  WiFi.mode(WIFI_MODE_STA);
  
  // Get MAC address as string
  String macStr = WiFi.macAddress();
  
  // Print standard format
  Serial.print("ESP32 MAC Address: ");
  Serial.println(macStr);
  Serial.println();
  
  // Parse and print in C array format
  Serial.println("Copy this into your code:");
  Serial.print("uint8_t broadcastAddress[] = {");
  
  // Parse each byte from the MAC address string
  for (int i = 0; i < 6; i++) {
    // Extract each hex pair (e.g., "08", "D1", etc.)
    String hexByte = macStr.substring(i * 3, i * 3 + 2);
    
    // Convert to integer and print with 0x prefix
    Serial.print("0x");
    Serial.print(hexByte);
    
    // Add comma except for last element
    if (i < 5) {
      Serial.print(",");
    }
  }
  
  Serial.println("};");
}

void loop() {
  // Empty loop
}

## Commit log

2026-01-09 Initial commit: ESP32 Mecanum Robot Car with remote control
    - Complete mecanum wheel robot car controller (Experiment_car_copy)
    - Wireless remote control with TFT display (ESP_NOW_remote)
    - 6 driving modes with omnidirectional movement
    - RGB LED status indicators (battery, mode, flapper, speed limiter)
    - Servo flapper mechanism
    - Real-time battery monitoring
    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
2026-01-09 Update motor and battery details in README
    Corrected battery and motor specifications in the Robot Car section.
2026-01-10 Remove detailed model descriptions from README
    Removed specific model descriptions for ESP32 mount, motor driver bracket, battery holder, and LED strip mount.
2026-01-10 Update battery type from LiPo to Li-ion for car
2026-01-10 Rename resistive divider for car.jpeg to resistivedividerforcar.jpeg
2026-01-10 Rename pin marking using nail polish.jpeg to pinmarkingusingnailpolish.jpeg
2026-01-10 Rename pin marking using whitener.jpeg to pinmarkingusingwhitener.jpeg
2026-01-10 Rename 3D_Models/BO Motor Mecanum Coupler - Aditya Rao (1).stl to couplerbyadityarao.stl
    [couplerbyadityarao.stl]
2026-01-10 Remove duplicate coupler file
    [couplerbyadityarao.stl]
2026-01-10 Add MAC address utility tool
    - Displays ESP32 MAC address in standard format
    - Outputs ready-to-use C array format for ESP-NOW
    - Useful for configuring broadcastAddress in car/remote code
2026-02-06 Add Telnet debugging and improve power architecture documentation
